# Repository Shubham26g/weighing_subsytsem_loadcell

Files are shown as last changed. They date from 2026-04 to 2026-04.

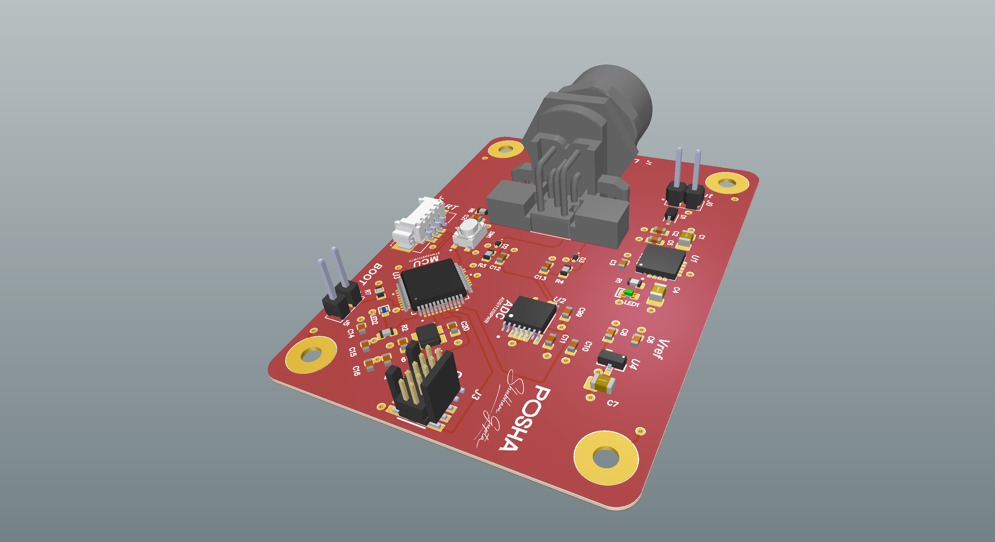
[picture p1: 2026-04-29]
Posha_V2_3.png

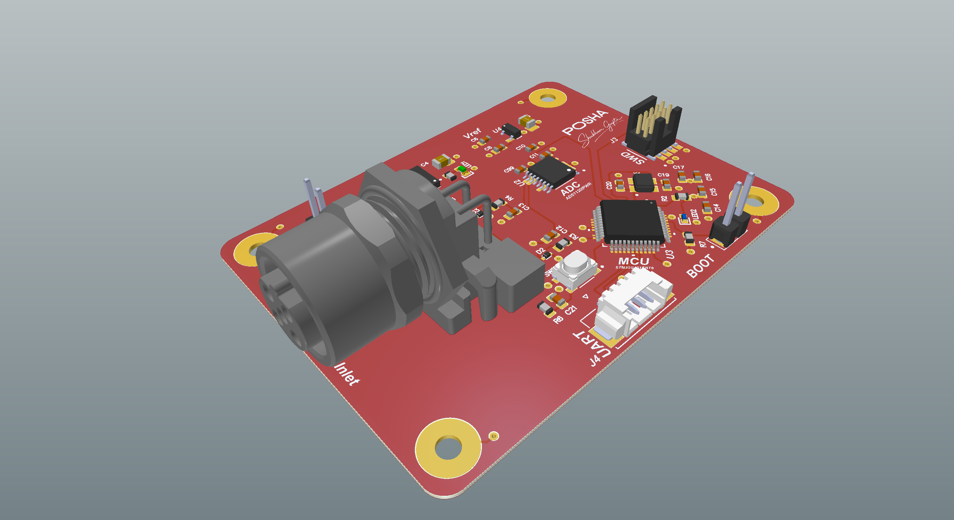
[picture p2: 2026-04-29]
Posha_V2_4.png

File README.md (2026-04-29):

# Precision Weighing Subsystem — Ratiometric Load Cell Interface

A high-resolution weighing system designed for automated food dispensing applications, built around the ADS1220 24-bit Σ-Δ ADC and STM32G431 microcontroller. Achieves **0.005 g/step resolution** through ratiometric measurement and precision analog front-end design.



---

## System Overview

```
                        ┌──────────────────────────────────────────────┐
                        │              STM32G431 MCU                   │
                        │                                              │
  ┌─────────────┐       │   ┌──────────┐    ┌──────────┐    ┌──────┐  │
  │  Tedea-1042  │──M12──│──►│ TVS+RC   │───►│ ADS1220  │───►│ SPI  │  │
  │  Load Cell   │       │   │ Filter   │    │ 24-bit   │    │ +DMA │  │
  │  (5 kg, IP67)│       │   └──────────┘    │ PGA=128× │    └──────┘  │
  └─────────────┘       │                    └────┬─────┘              │
                        │                         │                    │
                        │   ┌──────────┐    ┌─────┴─────┐             │
                        │   │TPS7A3301 │    │  REF3033   │             │
                        │   │  LDO     │    │  Voltage   │─── Excites  │
                        │   │ 4.4µVrms │    │  Reference │    Load Cell│
                        │   └──────────┘    │  ±0.05%   │             │
                        │                    └───────────┘             │
                        └──────────────────────────────────────────────┘
```

## Key Specifications

| Parameter | Value |
|---|---|
| **Resolution** | 0.005 g/step (20.4 noise-free bits) |
| **Capacity** | 5 kg (Tedea-Huntleigh 1042) |
| **ADC** | ADS1220 — 24-bit Σ-Δ, SPI, PGA = 128× |
| **Data Rate** | 20 SPS (configurable up to 2000 SPS) |
| **Excitation** | REF3033 precision reference (±0.05%, 10 ppm/°C) |
| **MCU** | STM32G431 (bare-metal, SPI + DMA) |
| **Environment** | IP67 load cell, industrial-grade components (-40 to +125°C) |
| **Accuracy** | ±1 g (system level, after calibration) |

---

## Signal Chain

```
Food on pan
    │
    ▼
Load Cell (Wheatstone Bridge)
    │  Output: 0 – 6.6 mV differential
    │  (2 mV/V × 3.3V excitation)
    ▼
Shielded Cable (4-wire, PTFE jacket)
    │
    ▼
M12 Connector (IP67, gold contacts)
    │
    ▼
TVS Diodes (PESD5V0S1BSF) — ESD protection
    │
    ▼
RC Filter (100Ω + 10nF, fc ≈ 159 kHz) — EMI rejection
    │
    ▼
ADS1220 PGA (128×) — 6.6 mV → 845 mV
    │
    ▼
ADS1220 Σ-Δ ADC — 24-bit digitization
    │  50/60 Hz rejection enabled
    ▼
SPI + DMA → STM32G431
    │
    ▼
Firmware: Tare → Calibration → Moving Average (N=10)
    │
    ▼
Weight output (grams)
```

---

## Hardware Design

### Component Selection

| Component | Part Number | Why Selected |
|---|---|---|
| **Load Cell** | Tedea-Huntleigh 1042 | IP67 stainless steel, OIML C3 certified, ±0.016% creep, 300% ultimate overload |
| **ADC** | TI ADS1220 | 24-bit Σ-Δ, external reference input (ratiometric), PGA 1×–128×, SPI interface |
| **Voltage Reference** | TI REF3033 | ±0.05% accuracy, 10 ppm/°C drift, 15 µVpp noise — excites load cell AND serves as ADC reference |
| **LDO** | TI TPS7A3301 | 4.4 µVrms output noise, 72 dB PSRR — clean digital power for MCU and ADC |
| **ESD Protection** | Nexperia PESD5V0S1BSF | TVS diodes on analog inputs — clamp transients before ADC |
| **Connector** | M12 (IP67) | Screw-lock, gold contacts — reliable in humid kitchen environment |

### Ratiometric Measurement

The REF3033 simultaneously:
1. **Excites** the load cell bridge (E+ / E-)
2. **Serves as** the ADC's voltage reference (REFP0 / REFN0)

If the reference drifts by +0.1%:
- Load cell output increases by 0.1%
- ADC reference increases by 0.1% → reads 0.1% lower
- **Errors cancel → zero drift in weight reading**

This is the single most important design decision — it eliminates reference voltage drift as an error source.

### Power Architecture

```
5V Input (Robot PSU)
    │
    ├──► TPS7A3301 LDO ──► 3V3 (Digital)
    │         │                  └── STM32G431, ADS1220 DVDD, LEDs
    │         │
    └──► REF3033 ──► VREF_3V3 (Precision Analog)
                         ├── Load Cell Excitation (E+)
                         └── ADC Reference (REFP0)
```

> **VREF_3V3 and 3V3 are separate nets.** Digital 3V3 has ~4.4 µVrms noise (acceptable for logic). VREF_3V3 has 15 µVpp noise (0.1–10 Hz) — required for exciting a µV-level sensor.

---

## Firmware

### Architecture

```
main.c
├── ads1220_driver.c/h    — SPI register config, DMA read, DRDY interrupt
├── weight.c/h            — Tare, calibration, filtering, gram conversion
├── uart_cli.c/h          — Serial command interface ($TARE, $CAL, $READ)
└── system_init.c/h       — Clock, GPIO, SPI, DMA peripheral setup
```

### ADS1220 Configuration

```c
// CONFIG0: AIN0/AIN1 differential, PGA=128×, PGA enabled
ads1220_write_reg(CONFIG0, 0x0E);

// CONFIG1: 20 SPS, normal mode, continuous conversion
ads1220_write_reg(CONFIG1, 0x04);

// CONFIG2: External reference (REFP0/REFN0), 50/60 Hz rejection
ads1220_write_reg(CONFIG2, 0x40);

// CONFIG3: DRDY on dedicated pin
ads1220_write_reg(CONFIG3, 0x00);
```

### Weight Calculation

```c
// Read 24-bit signed ADC value via SPI+DMA
int32_t raw = ads1220_read();

// Apply tare offset (captured at startup with empty pan)
int32_t tared = raw - tare_offset;

// Convert to grams using calibration factor
// cal_factor = (known_weight_raw - tare_raw) / known_weight_grams
float weight_g = (float)tared / cal_factor;

// Moving average filter (N=10) for noise smoothing
float filtered = moving_avg_update(&filter, weight_g);
```

### Serial Command Interface

| Command | Function |
|---|---|
| `$TARE` | Zero the scale with current load |
| `$CAL,<grams>` | Two-point calibration with known weight |
| `$READ` | Single filtered weight reading |
| `$RATE,<sps>` | Change ADC data rate (20/45/90/175/330/600) |
| `$RAW` | Read raw ADC counts (debugging) |

---

## PCB Design

### Layout Guidelines Followed

- **Separated analog and digital ground domains** — joined at a single point under the ADC
- **REF3033 and ADS1220 decoupling caps** placed within 3 mm of power pins (100nF C0G + 10µF X7R)
- **No signal traces routed under ADS1220** on bottom layer — unbroken ground plane for clean return paths
- **Analog input traces (AIN0/AIN1)** routed away from SPI clock — minimum 2 mm clearance
- **Guard ring** around analog inputs to prevent leakage current
- **M12 connector shield** tied to chassis ground through 0Ω resistor (configurable)

### Design Rules

| Parameter | Value |
|---|---|
| Layers | 4-layer (SIG-GND-PWR-SIG) |
| Min trace width | 6 mil (signal), 15 mil (power) |
| Min clearance | 6 mil |
| Via size | 0.3 mm drill / 0.6 mm pad |
| Impedance control | Not required (low-speed SPI ≤ 2 MHz) |

---

## Load Cell vs ADC Trade-off Analysis

### Load Cell Comparison

| Model | IP Rating | Accuracy | Creep (30 min) | Overload | Score |
|---|---|---|---|---|---|
| **Tedea 1042** ✅ | **IP67** | **±0.02% (OIML C3)** | **±0.016%** | **300%** | **4.55** |
| HBM SP4MC3 | IP67 | ±0.017% | ±0.014% | 300% | 4.20 |
| TAL220B | None | ±0.1% | ±0.05% | 200% | 2.05 |

### ADC Comparison

| ADC | Resolution | Interface | Ext. Ref | PGA | Score |
|---|---|---|---|---|---|
| **ADS1220** ✅ | **24-bit (20.4 NFB)** | **SPI** | **Yes** | **1–128×** | **4.65** |
| AD7190 | 24-bit (21.7 NFB) | SPI | Yes | 1–128× | 4.55 |
| HX711 | 24-bit (18 NFB) | Proprietary | No | 64/128× | 1.65 |

---

## Resolution Budget

```
Load Cell:     5000 g full scale
Sensitivity:   2 mV/V × 3.3V = 6.6 mV full-scale output
PGA:           128× → 845 mV at ADC input
ADC:           20.4 noise-free bits → 1,384,000 effective levels

Resolution = 5000 g ÷ 1,384,000 = 0.0036 g/step ≈ 0.005 g (conservative)

At 1g load:    Output = 1.32 µV | ADC noise floor = 0.09 µV | SNR = 14.7:1 ✓
```

---

## Environment & Reliability

| Challenge | Mitigation |
|---|---|
| Kitchen humidity & grease | IP67 load cell + M12 sealed connector |
| Heat from cooking (200°C pan) | PTFE thermal insulator between pan and load cell |
| Motor vibration | Rubber isolators + digital moving-average filter |
| Mains EMI (50/60 Hz) | ADS1220 built-in 50/60 Hz rejection + shielded cable |
| ESD from user contact | TVS diodes (PESD5V0S1BSF) on all analog inputs |
| 15 kg accidental overload | 300% ultimate overload rating + mechanical hard stops |

---

## Tools Used

- **MCU IDE:** STM32CubeIDE (bare-metal, no HAL for SPI — register-level driver)
- **PCB Design:** Altium Designer
- **Simulation:** LTspice (analog front-end noise analysis)
- **Component Sourcing:** Mouser/Digikey (genuine TI, Vishay, Nexperia parts)
- **Version Control:** Git

---

## References

- [ADS1220 Datasheet](https://www.ti.com/lit/ds/symlink/ads1220.pdf) — TI, 24-bit Σ-Δ ADC
- [REF3033 Datasheet](https://www.ti.com/lit/ds/symlink/ref3033.pdf) — TI, 3.3V Precision Reference
- [TPS7A3301 Datasheet](https://www.ti.com/lit/ds/symlink/tps7a33.pdf) — TI, Low-Noise LDO
- [Tedea-Huntleigh 1042 Datasheet](https://www.vishay.com/docs/12082/1042.pdf) — Vishay, Single-Point Load Cell
- [OIML R60 Standard](https://www.oiml.org/en/files/pdf_r/r060-e00.pdf) — Metrological Regulation for Load Cells

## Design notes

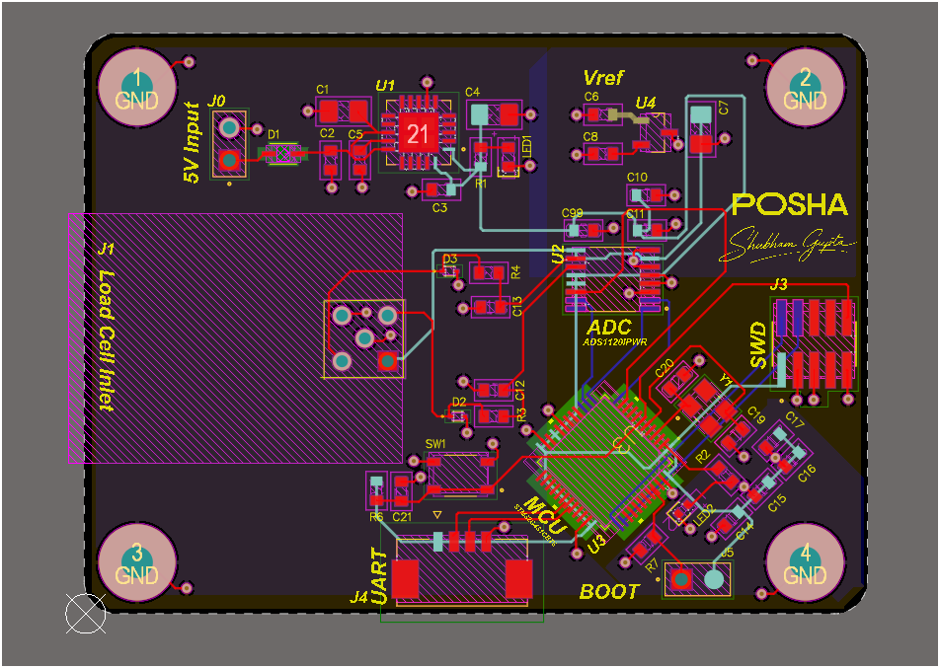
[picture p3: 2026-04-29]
Screenshot 2026-04-02 203027.png

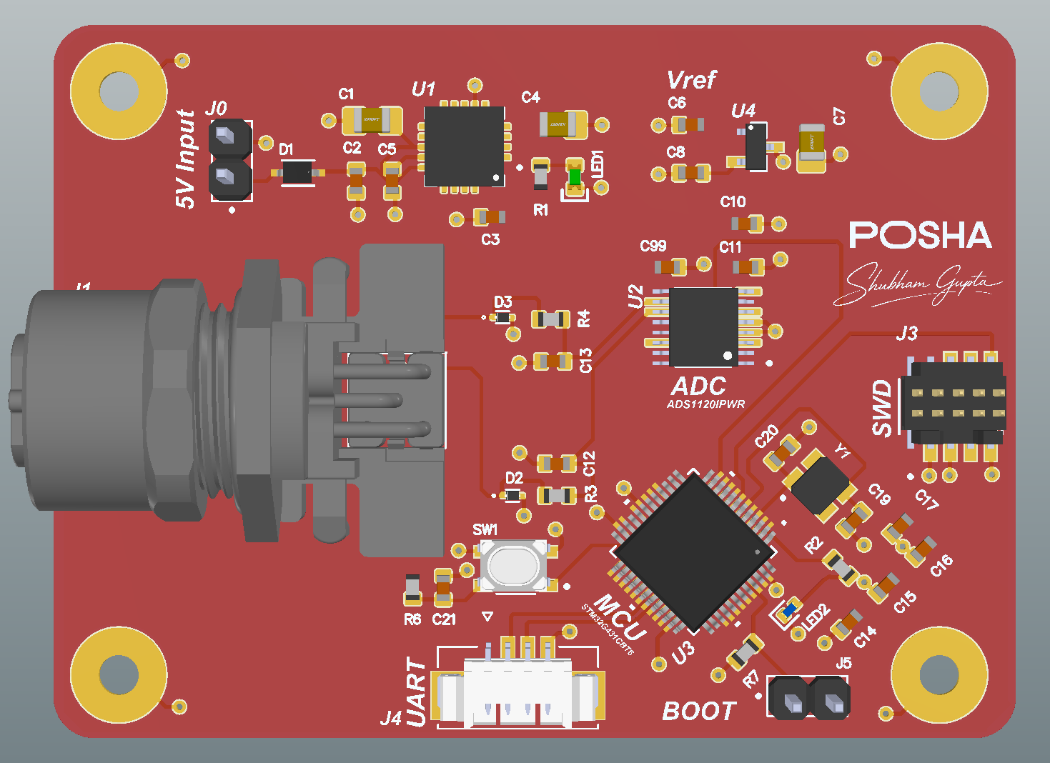
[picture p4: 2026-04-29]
Posha_v2_1.png

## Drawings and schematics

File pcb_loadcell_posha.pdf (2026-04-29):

# POSHA

# Electronic Engineering Internship Assignment

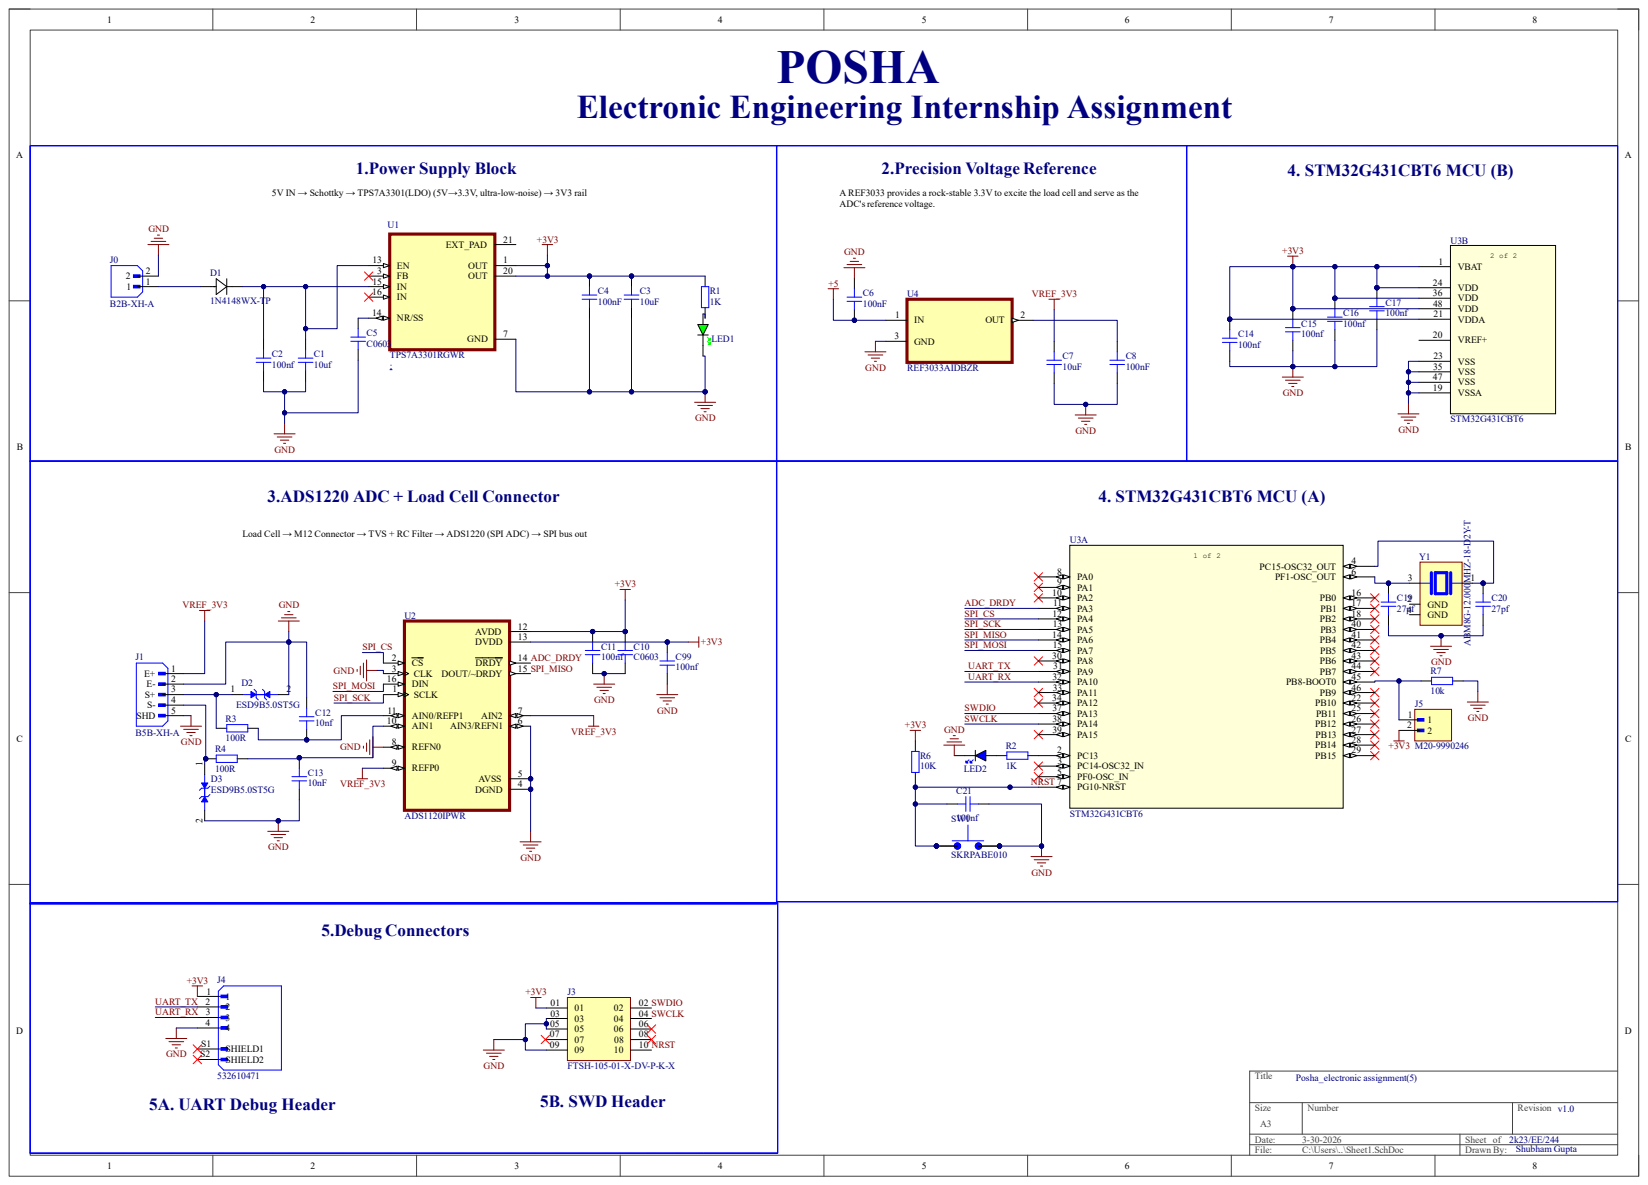
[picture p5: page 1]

5V IN → Schottky → TPS7A3301(LDO) (5V→3.3V, ultra-low-noise) → 3V3 rail

A REF3033 provides a rock-stable 3.3V to excite the load cell and serve as the
ADC's reference voltage.

3.ADS1220 ADC + Load Cell Connector

Load Cell → M12 Connector → TVS + RC Filter → ADS1220 (SPI ADC) → SPI bus out
